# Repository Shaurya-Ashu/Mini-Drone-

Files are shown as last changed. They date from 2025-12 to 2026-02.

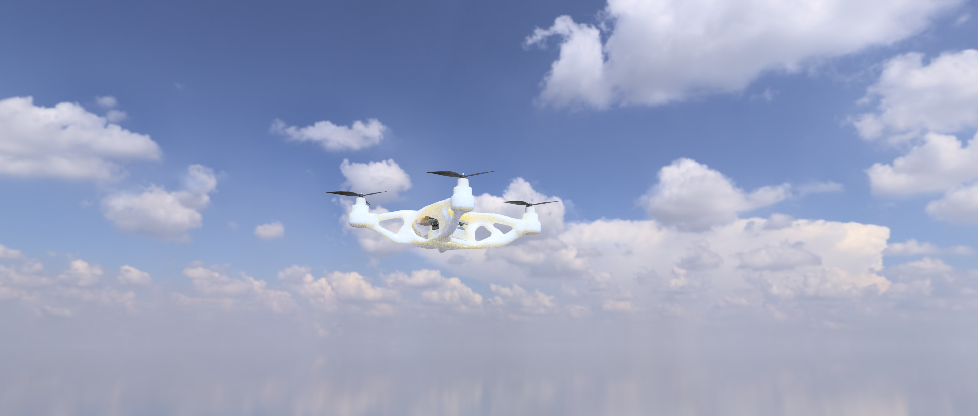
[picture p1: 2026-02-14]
CAD/Genrative Design Esp32S3 Drone Frame v2.png

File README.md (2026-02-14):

# About me 
Hi this is Shaurya a young innovator 
I like to make smart & cool project , and specially i am fascinated by flying things
So , today i am here try to make some things that can flys .
# Mini-Drone-
Genrative Design Esp32S3 Drone Frame v1

simple_frame_v1_2026-Feb-14_08-37-48PM-000_CustomizedView30675265595_png

It's a mini quadcopter powered by 
- Xiao ESP32 S3 (FC)
- MPU 6050
- 8520 Coreless Motor 2xCW & 2xCCW
- 55mm Propeller 2xCW & 2xCCW
- Coustom motor drive:
    • SI2300 1N-MOSFET 4x
    • 1N4148 Diode 4x
    • 10k ohm Resistor 4X

- CRSF reciver (I will be using RadioMaster XR2 Nano )
- A transmitter supporting you Reciver ( I have an Radio Master Pocket)

# Frame
There are two frames one generative designed and other is 3d moduled 
The first frame is generative designed 3D modeled in Fusion 360 Edu 
It looks so greate 
Genrative_Design_Esp32S3_Drone_Frame_2026-Feb-13_04-50-57PM-000_CustomizedView5716981986_png_alpha

The second is a Simple Dron Frame
simple_frame_v1_2026-Feb-14_08-45-50PM-000_CustomizedView12917580278_png

The housing is designed to fit all the component including battery, and the receiver is kept at the top with an open  antenna.
# Schematics
  Screenshot 2026-02-12 at 12 55 18 PM

  Here is the break down of the connections 
  MOTORS-
  M1 --> A8
  M2 --> A3
  M3 --> A2
  M4 --> A0

  MPU6050-
  SDA --> A4
  SCL --> A5

  CRSF-
  RX --> D7
  TX --> D6

  3.7v to 5v-
  for reciver to get powered 

  led-
  2 power led
  1 arm led

  Battery Voltage Telemetry-
  Vin --> A1

# PCB 
The PCB is designed in Kicad V9 

top render-

Screenshot 2026-02-13 at 7 20 46 PM

bottom render-

Screenshot 2026-02-13 at 7 20 58 PM

The connection for the motors are on top
and for crsf at top , battry at bottom

Screenshot 2026-02-13 at 7 21 10 PM

# Assembly
  The whole thing is designed to be fitted into that frame , it's all going to be secured by a damping screw. A zip tie for battery just to be secured, and the below given image shows how each component is placed in their.
  
  First Frame
  Screenshot 2026-02-14 at 9 21 31 AM
 
 Second Frame
  Screenshot 2026-02-15 at 2 11 53 AM

# Firmware

This project uses open-source flight controller firmware from the ESP-FC project,
developed by rtlopez.

- Original firmware repository:
  https://github.com/rtlopez/esp-fc

- My fork :
  https://github.com/Shaurya-Ashu/esp-fc-firmware-reference

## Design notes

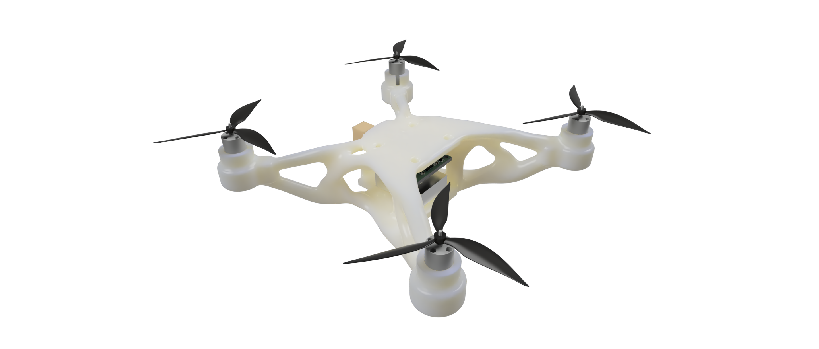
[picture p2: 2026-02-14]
CAD/Genrative_Design_Esp32S3_Drone_Frame_2026-Feb-13_04-50-57PM-000_CustomizedView5716981986_png_alpha.png

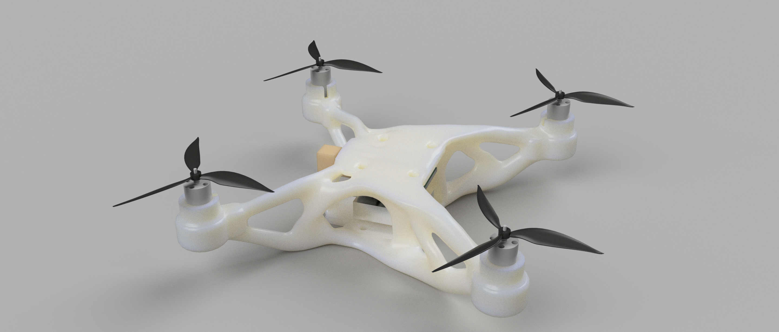
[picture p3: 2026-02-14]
CAD/Genrative Design Esp32S3 Drone Frame v1.png

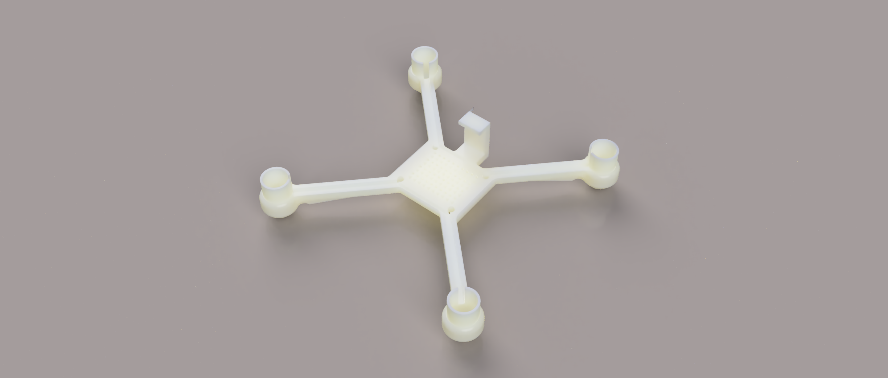
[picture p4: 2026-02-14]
CAD/simple_frame_v1_2026-Feb-14_08-45-50PM-000_CustomizedView12917580278_png.png

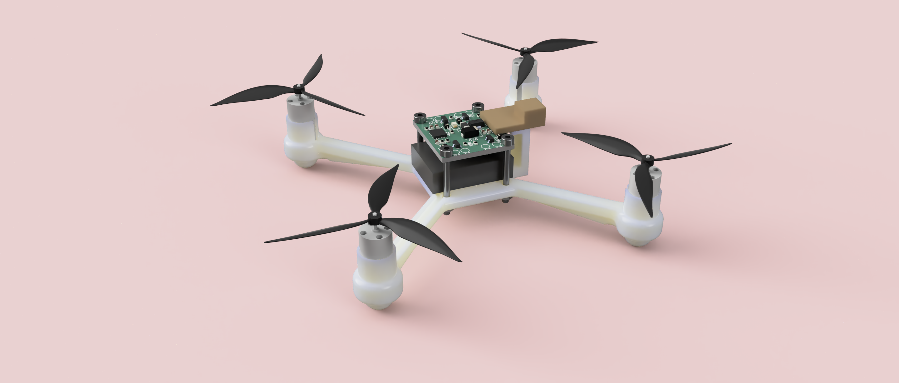
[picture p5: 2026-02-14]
CAD/simple_frame_v1_2026-Feb-14_08-37-48PM-000_CustomizedView30675265595_png.png

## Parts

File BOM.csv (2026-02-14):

Item | Description | Quantity | Unit Price($) | Total Price($) | URL
XIAO ESP32 S3 | Flight Controller | 1 | 8.82 | 8.82 | https://robocraze.com/products/seeed-studio-xiao-esp32-s3-development-board-supports-wi-fi-bluetooth-5-0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
8520 Coreless Brushed Motor | Motors | 1 set(4Pcs) | 6.45 | 6.45 | https://roboticsdna.in/product/coreless-motors-720-series-45000-rpm-3-7v/
55 mm Blade Propeller | Propeller | 1set(4Pcs) | 0.56 | 0.56 | https://roboticsdna.in/product/4pcs-set-55mm-white-propeller-for-h107l-h107c-h107d（aperture-1mm）/
1N SI2300 MOSFET | To drive motor | 4 | 0.046 | 0.19 | https://robu.in/product/si2300-hxy-mosfet-20v-6a-350mw-27mω4-5v-500mv-1-n-channel-sot-23-mosfets-rohs/
1N4148 SMD | Diode | 4 | 0.026 | 0.10 | https://robu.in/product/ac1206fr-0710kl-yageo-res-thick-film-1206-10k-ohm-1-0-25w1-4w-±100ppm-c-pad-smd-t-r-automotive-aec-q200/
10k ohm SMD | Resister | 5 | 0.0052 | 0.0262
1k ohm SMD | Resister | 4 | 0.0030 | 0.012
150 ohm SMD | Resister | 3 | 0.0011 | 0.0033
0.01uF SMD | Capacitor | 4 | 0.0030 | 0.012
LED 0805 SMD | Led | 3 | 0.029 | 0.097
ME2108A33P Module | Boost converter | 1 | 0.57 | 0.57 | https://www.flyrobo.in/1.5v-1.8v-2.5v-3v-3.3v-3.7v-4.2v-5v-dc-dc-dc-boost-converter-step-up-module
MPU6050 | Gyro and accelerometer | 1 | 1.91 | 1.91 | https://robu.in/product/mpu-6050-gyro-sensor-2-accelerometer/
1S 300mah battery | Battery | 1 | 1.92 | 1.92 | https://robu.in/product/wly702025-300mah-3-7v-single-cell-rechargeable-lipo-battery/
RadioMaster XR2 Nano | ELRS recover | 1 | 12.12 | 12.12 | https://rcmumbai.com/products/radiomaster-xr2-nano-2-4ghz-expresslrs-receiver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
PCB | Pcb | 5 | 4.9 | 4.9 | SeedStudio
Frame | 3d printing | 1 | 6.4 | 0.9 | 3D
 |  |  | Shipment | 4.56+ 1.66+0.76+0.54+0.65+0.54+1.66 =10.28
 |  |  | Tax(3Dprint & Motors |  | 2.52
 |  |  | Total= | 51.38 ~ 51.5

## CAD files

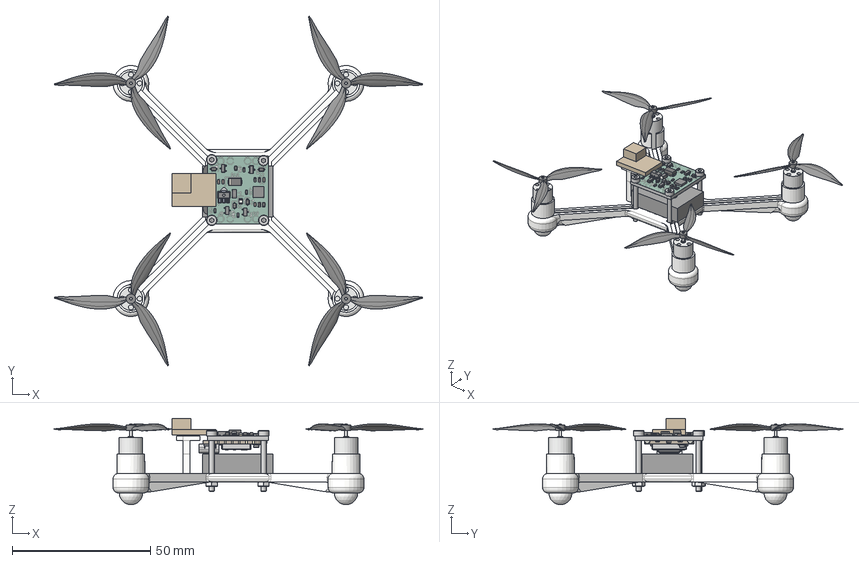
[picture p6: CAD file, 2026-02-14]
CAD/simple frame.step
133.1 x 126.5 x 31.2 mm
8520 Coreless Motor
Propaller
C_0603_1608Metric x 6
SI2300 x 4
R_0603_1608Metric x 12
D_SOD-323 x 4
MPU-6050
L_1206_3216Metric
LED_0805_2012Metric x 3
ME2108A33P
D_SMA
BOSS-EXTRUDE14_8_
BOSS-EXTRUDE7_4_
BOSS-EXTRUDE7_3_
BOSS-EXTRUDE14_4_
BOSS-EXTRUDE14_2_
BOSS-EXTRUDE14_11_
BOSS-EXTRUDE7_7_
BOSS-EXTRUDE14_9_
BOSS-EXTRUDE14_3_
BOSS-EXTRUDE14_7_
MIRROR2
BOSS-EXTRUDE14_5_
BOSS-EXTRUDE14_12_
BOSS-EXTRUDE7_8_
BOSS-EXTRUDE7_1_
BOSS-EXTRUDE14_10_
BOSS-EXTRUDE7_9_
BOSS-EXTRUDE14_6_
BOSS-EXTRUDE14_1_
BOSS-EXTRUDE7_6_
BOSS-EXTRUDE7_2_
CUT-EXTRUDE5
BOSS-EXTRUDE7_5_
Shield
Pins x 2
U.FL-R-SMT-1_10_ v1
EspS3Drone_silkscreen
EspS3Drone_silkscreen_1
EspS3Drone_soldermask
EspS3Drone_soldermask_1
EspS3Drone_PCB
8520 Coreless Motor_1
Propaller_1
8520 Coreless Motor_2
Propaller_2
8520 Coreless Motor_3
Propaller_3
ISO 4762 - M2 x 20 Steel 4.6 Plain x 4
DIN EN ISO 4032 - M2 Steel 6 Plain x 4
frame
battery
reciver

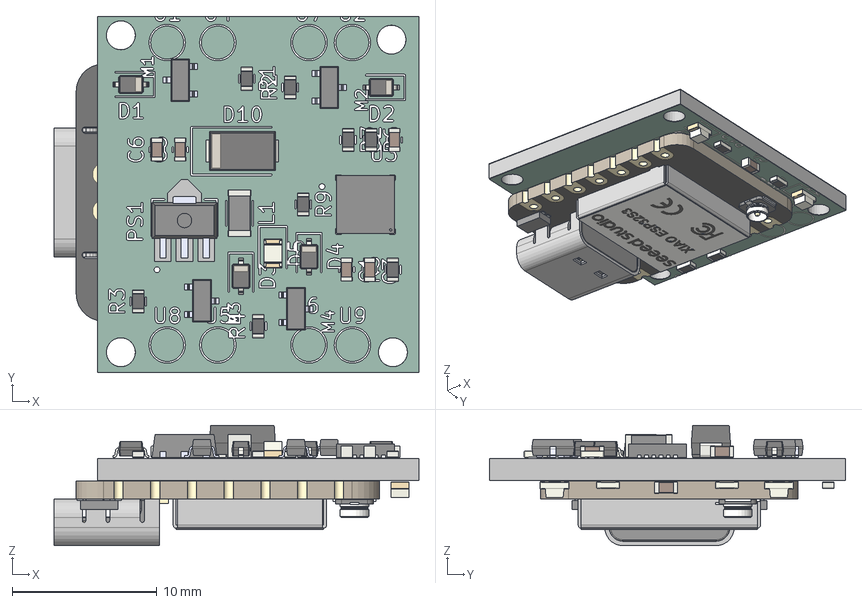
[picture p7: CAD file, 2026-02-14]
PCB/EspS3Drone.step
25.2 x 24.6 x 8.31 mm
C_0603_1608Metric x 6
SI2300 x 4
R_0603_1608Metric x 12
D_SOD-323 x 4
MPU-6050
L_1206_3216Metric
LED_0805_2012Metric x 3
ME2108A33P
D_SMA
BOSS-EXTRUDE14_8_
BOSS-EXTRUDE7_4_
BOSS-EXTRUDE7_3_
BOSS-EXTRUDE14_4_
BOSS-EXTRUDE14_2_
BOSS-EXTRUDE14_11_
BOSS-EXTRUDE7_7_
BOSS-EXTRUDE14_9_
BOSS-EXTRUDE14_3_
BOSS-EXTRUDE14_7_
MIRROR2
BOSS-EXTRUDE14_5_
BOSS-EXTRUDE14_12_
BOSS-EXTRUDE7_8_
BOSS-EXTRUDE7_1_
BOSS-EXTRUDE14_10_
BOSS-EXTRUDE7_9_
BOSS-EXTRUDE14_6_
BOSS-EXTRUDE14_1_
BOSS-EXTRUDE7_6_
BOSS-EXTRUDE7_2_
CUT-EXTRUDE5
BOSS-EXTRUDE7_5_
Shield
Pins x 2
U.FL-R-SMT-1_10_ v1
EspS3Drone_silkscreen x 2
EspS3Drone_soldermask x 2
EspS3Drone_PCB

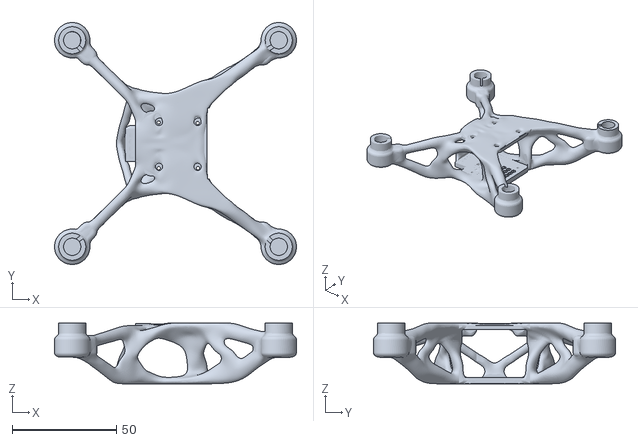
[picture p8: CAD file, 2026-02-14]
CAD/Genrative Design Esp32S3 Drone Frame.stl
116.0 x 116.0 x 29.2

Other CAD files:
CAD/simple frame.stl

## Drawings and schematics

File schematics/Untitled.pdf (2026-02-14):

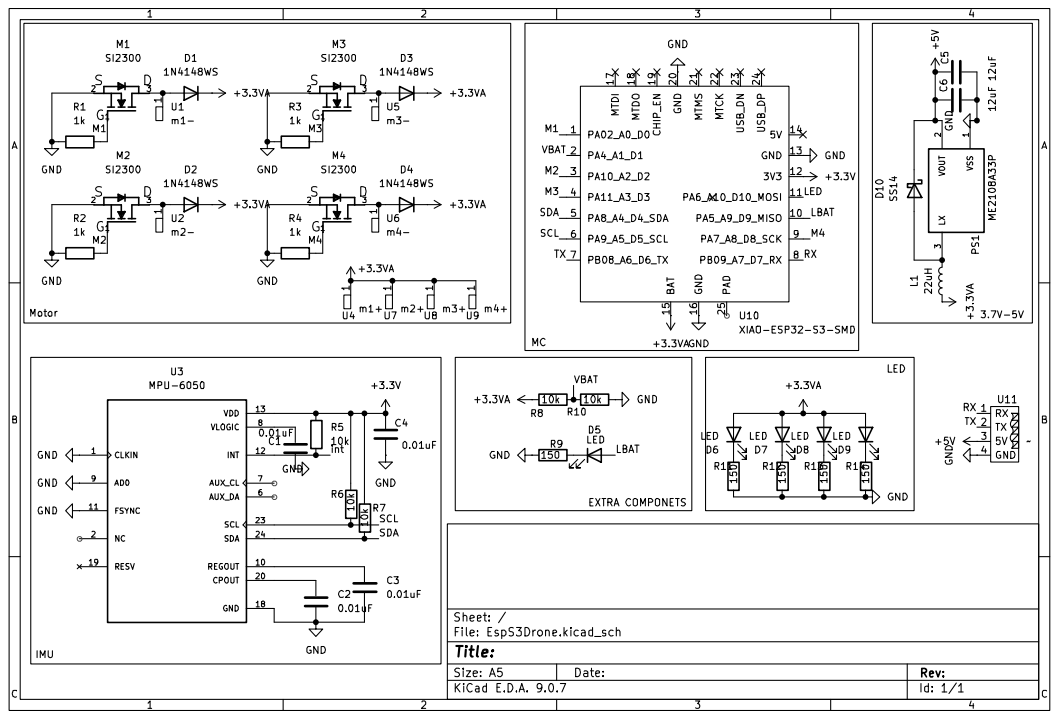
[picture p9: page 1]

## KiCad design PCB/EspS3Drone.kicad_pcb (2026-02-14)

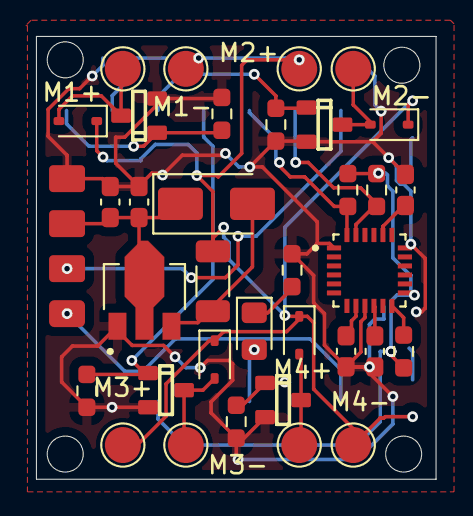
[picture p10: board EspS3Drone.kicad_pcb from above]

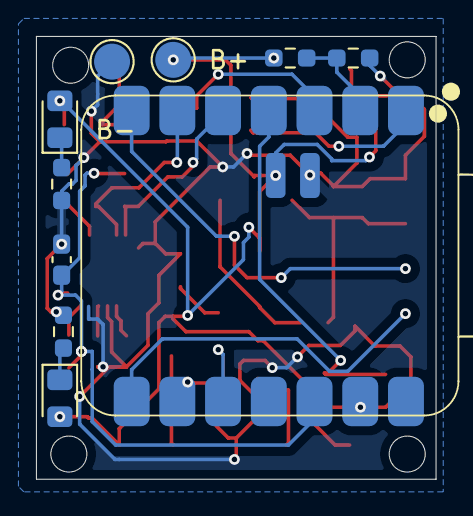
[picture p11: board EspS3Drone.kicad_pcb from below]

Board: 2 copper layers, 22.2 x 24.6 mm, 45 parts (10 on the bottom side), 26 nets.

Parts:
B+: B+; TestPoint_Pad_D2.0mm
B-: B-; TestPoint_Pad_D2.0mm
C1, C2, C3, C4: 0.01uF; C_0603_1608Metric_Pad1.08x0.95mm_HandSolder
C5, C6: 12uF; C_0603_1608Metric_Pad1.08x0.95mm_HandSolder
D1, D2, D3, D4: 1N4148WS; D_SOD-323
D5, D6, D7: LED; LED_0805_2012Metric_Pad1.15x1.40mm_HandSolder
D10: SS14; D_SMA
L1: 22uH; L_1206_3216Metric_Pad1.22x1.90mm_HandSolder
M1, M2, M3, M4: SI2300; SOT23_1_
M1+: m1-; TestPoint_Pad_D2.0mm
M1-: m1+; TestPoint_Pad_D2.0mm
M2+: m2+; TestPoint_Pad_D2.0mm
M2-: m2-; TestPoint_Pad_D2.0mm
M3+: m3+; TestPoint_Pad_D2.0mm
M3-: m3-; TestPoint_Pad_D2.0mm
M4+: m4-; TestPoint_Pad_D2.0mm
M4-: m4+; TestPoint_Pad_D2.0mm
PS1: ME2108A33P; CONV_ME2108A33P
R1, R2, R3, R4: 1k; R_0603_1608Metric_Pad0.98x0.95mm_HandSolder
R5, R6, R7, R8, R10: 10k; R_0603_1608Metric_Pad0.98x0.95mm_HandSolder
R9, R11, R12: 150; R_0603_1608Metric_Pad0.98x0.95mm_HandSolder
U3: MPU-6050; QFN50P400X400X95-24N
U10: XIAO-ESP32-S3-SMD; XIAO-ESP32-S3-SMD_PAD
U11: XR2 NANO

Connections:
+3.3V: C4.1, R5.1, R6.1, R7.1, U3.13 (VDD), U10.12 (3V3)
+3.3VA: B+.1, D1.1 (K), D2.1 (K), D3.1 (K), D4.1 (K), D6.2 (A), D7.2 (A), L1.1, M1-.1, M2+.1, M3+.1, M4-.1, R8.1, U10.15 (BAT)
+5V: C5.1, C6.1, D10.1 (K), PS1.2 (VOUT), U11.3 (5V)
/LBAT: D5.2 (A), U10.10 (PA5_A9_D9_MISO)
/M1: M1.1, R1.2, U10.1 (PA02_A0_D0)
/M2: M2.1, R2.2, U10.3 (PA10_A2_D2)
/M3: M3.1, R3.2, U10.4 (PA11_A3_D3)
/M4: M4.1, R4.2, U10.9 (PA7_A8_D8_SCK)
/RX: U10.8 (PB09_A7_D7_RX), U11.1 (RX)
/SCL: R6.2, U3.23 (SCL), U10.6 (PA9_A5_D5_SCL)
/SDA: R7.2, U3.24 (SDA), U10.5 (PA8_A4_D4_SDA)
/TX: U10.7 (PB08_A6_D6_TX), U11.2 (TX)
/VBAT: R8.2, R10.1, U10.2 (PA4_A1_D1)
/int: R5.2, U3.12 (INT)
GND: B-.1, C1.2, C2.2, C3.2, C4.2, C5.2, C6.2, M1.2, M2.2, M3.2, M4.2, PS1.1 (VSS), R1.1, R2.1, R3.1, R4.1, R9.1, R10.2, R11.2, R12.2, U3.1 (CLKIN), U3.9 (AD0), U3.11 (FSYNC), U3.18 (GND), U10.13 (GND), U10.16 (GND), U11.4 (GND)
unnamed: D1.2 (A), M1.3, M1+.1
unnamed: D2.2 (A), M2.3, M2-.1
unnamed: D3.2 (A), M3.3, M3-.1
unnamed: D4.2 (A), M4.3, M4+.1
unnamed: D5.1 (K), R9.2
unnamed: D6.1 (K), R11.1
unnamed: D7.1 (K), R12.1
unnamed: D10.2 (A), L1.2, PS1.3 (LX)
unnamed: C2.1, U3.20 (CPOUT)
unnamed: C3.1, U3.10 (REGOUT)
unnamed: C1.1, U3.8 (VLOGIC)

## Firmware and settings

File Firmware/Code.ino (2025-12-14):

#include <WiFi.h>
#include <esp_now.h>
#include <Wire.h>
#include <MPU6050.h>

MPU6050 mpu;


#define M1_PIN 0
#define M2_PIN 2
#define M3_PIN 3
#define M4_PIN 8


#define CH1 0
#define CH2 1
#define CH3 2
#define CH4 3

#define PWM_FREQ 25000
#define PWM_RES 8   


#define MOTOR_MIN 25     
#define MOTOR_MAX 240
#define MOTOR_ARM 15


float kp = 0.18;
float ki = 0.00;
float kd = 0.003;


typedef struct {
  int throttle;
  int roll;
  int pitch;
  int yaw;
  bool armed;
} ControlData;

ControlData rx;


float rollPID, pitchPID, yawPID;
float rollError, pitchError, yawError;
float lastRollErr, lastPitchErr, lastYawErr;


float gx, gy, gz;
unsigned long lastTime;

void onReceive(const esp_now_recv_info_t *info, const uint8_t *data, int len) {
  memcpy(&rx, data, sizeof(rx));
}

void setup() {
  Serial.begin(115200);

  WiFi.mode(WIFI_STA);
  esp_now_init();
  esp_now_register_recv_cb(onReceive);

  
  Wire.begin();
  mpu.initialize();
  mpu.setFullScaleGyroRange(MPU6050_GYRO_FS_1000);

  
  ledcSetup(CH1, PWM_FREQ, PWM_RES);
  ledcSetup(CH2, PWM_FREQ, PWM_RES);
  ledcSetup(CH3, PWM_FREQ, PWM_RES);
  ledcSetup(CH4, PWM_FREQ, PWM_RES);

  ledcAttachPin(M1_PIN, CH1);
  ledcAttachPin(M2_PIN, CH2);
  ledcAttachPin(M3_PIN, CH3);
  ledcAttachPin(M4_PIN, CH4);

  lastTime = micros();
}

void loop() {
  
  if (!rx.armed) {
    stopAllMotors();
    return;
  }


  float dt = (micros() - lastTime) / 1000000.0;
  lastTime = micros();

  
  mpu.getRotation(&gx, &gy, &gz);
  rollRate  = gx / 131.0;
  pitchRate = gy / 131.0;
  yawRate   = gz / 131.0;

  
  rollError  = rx.roll  - rollRate;
  pitchError = rx.pitch - pitchRate;
  yawError   = rx.yaw   - yawRate;

  rollPID  = kp * rollError  + kd * ((rollError  - lastRollErr)  / dt);
  pitchPID = kp * pitchError + kd * ((pitchError - lastPitchErr) / dt);
  yawPID   = kp * yawError   + kd * ((yawError   - lastYawErr)   / dt);

  lastRollErr  = rollError;
  lastPitchErr = pitchError;
  lastYawErr   = yawError;

  int base = map(rx.throttle, 0, 255, MOTOR_MIN, MOTOR_MAX);

  // X quad motor mixing
  int m1 = base + pitchPID + rollPID - yawPID;
  int m2 = base + pitchPID - rollPID + yawPID;
  int m3 = base - pitchPID - rollPID - yawPID;
  int m4 = base - pitchPID + rollPID + yawPID;

  writeMotor(CH1, m1);
  writeMotor(CH2, m2);
  writeMotor(CH3, m3);
  writeMotor(CH4, m4);
}

void writeMotor(int ch, int val) {
  val = constrain(val, MOTOR_ARM, MOTOR_MAX);
  ledcWrite(ch, val);
}

void stopAllMotors() {
  ledcWrite(CH1, 0);
  ledcWrite(CH2, 0);
  ledcWrite(CH3, 0);
  ledcWrite(CH4, 0);
}

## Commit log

2025-12-14 Create PCB
2025-12-14 Add initial firmware for motor control and PID
2026-01-24 Replace frame image in README
    Updated image reference in the README for the frame section.
2026-02-14 Revise README with updated project details and images
    Updated images and descriptions for the mini-drone project, including frame, PCB, and assembly details.
2026-02-14 Enhance frame section with generative design details
    Updated the frame description to include details about generative design and Fusion 360.
2026-02-14 Add images for assembly frames in README
    Added images for the first and second frames in the Assembly section.
